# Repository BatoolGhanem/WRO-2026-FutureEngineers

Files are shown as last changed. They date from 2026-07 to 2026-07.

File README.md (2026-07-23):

<div align="center">

# 🏎️ WRO Future Engineers 2026

## NextGen Minds 🇵🇸

### Birzeit University — Palestine

Autonomous Ackermann Steering Robot for the **World Robot Olympiad (WRO) Future Engineers 2026** competition.

<p>
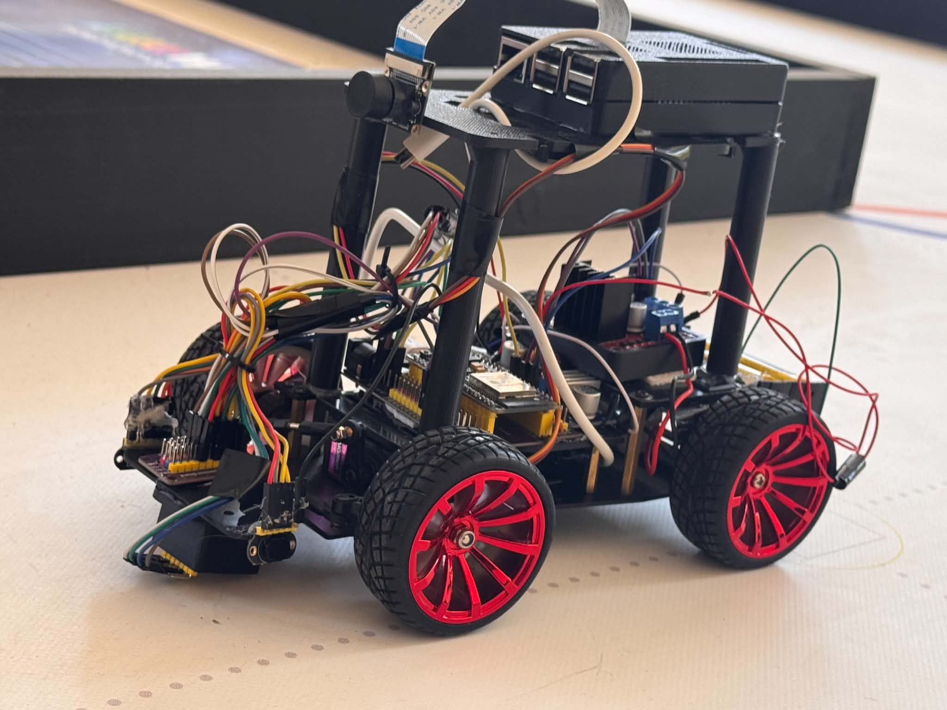
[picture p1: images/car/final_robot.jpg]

</p>

---







</div>

---

# Overview

This repository documents the complete development of our autonomous vehicle for the **WRO Future Engineers 2026** competition.

Rather than presenting only the final robot, this repository documents the complete engineering journey—from the first design discussions and component selection to mechanical assembly, electronics integration, software development, testing, calibration, and continuous improvement.

The robot is built on an Ackermann steering chassis and combines real-time embedded control using an ESP32 with higher-level vision processing on a Raspberry Pi.

---

# Robot Highlights

- Ackermann steering vehicle
- Rear-wheel drive
- ESP32 real-time controller
- Raspberry Pi vision processor
- Dual VL53L1X Time-of-Flight sensors
- MPU6050 inertial measurement unit
- TCS34725 color sensor
- Raspberry Pi Camera
- Modular hardware architecture
- UART communication between controllers
- Fully documented engineering process

---

# Competition

**Competition:** World Robot Olympiad (WRO)

**Category:** Future Engineers

**Season:** 2026

The robot is designed to complete both official challenges:

- Open Challenge
- Obstacle Challenge

---

# Team

<p align="center">
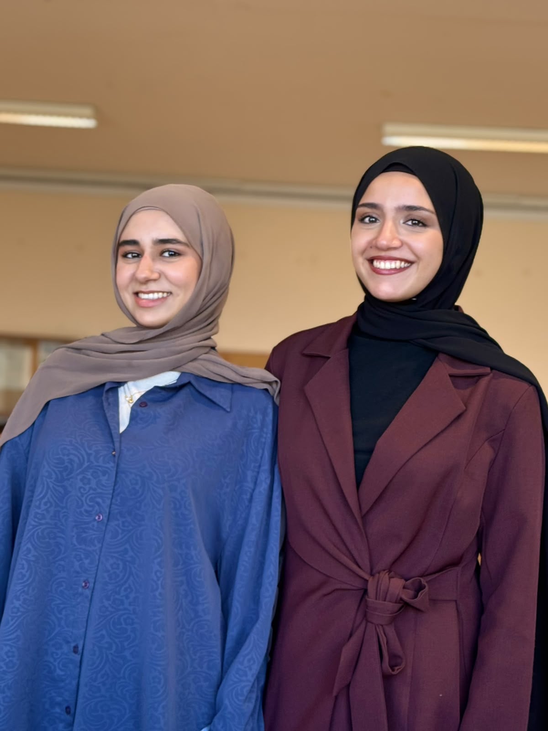
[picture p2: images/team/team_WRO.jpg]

</p>

We are **NextGen Minds**, a team of second-year Computer Engineering students from Birzeit University representing Palestine in the WRO Future Engineers 2026 competition.

For detailed information about our team members and responsibilities, see:

📄 **[TEAM.md](docs/TEAM.md)**

**Coach**

Osid Ali

**Institution**

Birzeit University

**Country**

Palestine 🇵🇸

---

# Robot Architecture

The robot follows a distributed architecture where each controller has a dedicated responsibility.

| Controller | Responsibilities |
|---|---|
| Raspberry Pi 3 Model B | Computer vision, obstacle detection, navigation logic |
| ESP32 DevKit V1 | Motor control, steering, sensor acquisition, real-time control |

Communication between both controllers is performed using UART serial communication.

This architecture separates computationally intensive vision algorithms from deterministic real-time vehicle control, resulting in a more reliable and modular system.

---

# Robot Specifications

| Parameter | Value |
|---|---:|
| Steering | Ackermann |
| Drive | Rear-Wheel Drive |
| Main Controller | ESP32 DevKit V1 |
| Vision Processor | Raspberry Pi 3 Model B |
| Camera | Raspberry Pi Camera |
| Motor Driver | L298N |
| Steering Servo | MG996R |
| Distance Sensors | 2 × VL53L1X |
| IMU | MPU6050 |
| Color Sensor | TCS34725 |
| Power System | 2S Li-ion Battery + XL4015 Buck Converter |

---

# Repository Structure

```text
WRO-2026-FutureEngineers/

├── README.md

├── docs/
│   ├── HARDWARE.md
│   ├── SOFTWARE.md
│   ├── WIRING.md
│   ├── TESTING.md
│   ├── CALIBRATION.md
│   ├── CALCULATIONS.md
│   ├── DECISIONS.md
│   ├── JOURNAL.md
│   └── TEAM.md

├── src/
│   ├── esp32/
│   └── raspberry_pi/

├── images/

└── videos/
```
# Hardware

The robot combines commercially available components with custom mechanical mounts to create a reliable and modular autonomous platform.

Every hardware component was selected after evaluating multiple alternatives based on performance, reliability, compatibility, availability, and future scalability.

For detailed specifications and engineering justification, see:

📄 **[Hardware Documentation](docs/HARDWARE.md)**

📄 **[Engineering Decisions](docs/DECISIONS.md)**

---

## Main Components

| Component | Model |
|---|---|
| Main Controller | ESP32 DevKit V1 |
| Vision Processor | Raspberry Pi 3 Model B |
| Camera | Raspberry Pi Camera Module |
| Motor Driver | L298N |
| Steering Servo | MG996R |
| Drive Motor | JGA25-370 DC Gear Motor |
| Distance Sensors | 2 × VL53L1X |
| IMU | MPU6050 |
| Color Sensor | TCS34725 |
| Power Supply | 2S Li-ion Battery |
| Voltage Regulator | XL4015 Buck Converter |

---

## Electronics

The electronics were designed around a distributed architecture.

The ESP32 performs all real-time tasks including:

- Steering control
- Motor control
- Sensor acquisition
- Safety functions

The Raspberry Pi performs computationally intensive tasks including:

- Camera processing
- Object detection
- Navigation logic
- Decision making

Both controllers communicate through a UART interface.

Complete wiring documentation is available in:

📄 **[WIRING.md](docs/WIRING.md)**

---

# Software

The software was developed as independent modules instead of a single monolithic program.

This modular design improves:

- Maintainability
- Debugging
- Reliability
- Future expansion

A clear separation exists between high-level vision processing and low-level embedded control.

For the complete software description, see:

📄 **[SOFTWARE.md](docs/SOFTWARE.md)**

---

## ESP32 Responsibilities

- Motor control
- Steering control
- Wall following
- Reading VL53L1X sensors
- Reading MPU6050
- Reading TCS34725
- Executing movement commands
- Communication with Raspberry Pi

---

## Raspberry Pi Responsibilities

- Image acquisition
- Computer vision
- Obstacle detection
- Navigation decisions
- UART communication

---

# Robot Capabilities

The robot is capable of:

- Autonomous driving
- Wall following
- Accurate 90° turns
- Obstacle detection
- Color marker recognition
- Heading correction using the IMU
- Real-time sensor fusion
- Modular software execution

---

# Engineering Documentation

This repository includes complete engineering documentation covering every stage of development.

| Document | Description |
|---|---|
| HARDWARE.md | Hardware components and specifications |
| SOFTWARE.md | Software architecture |
| WIRING.md | Electrical wiring diagram |
| DECISIONS.md | Engineering decision process |
| CALCULATIONS.md | Engineering calculations |
| TESTING.md | Testing methodology |
| CALIBRATION.md | Calibration procedure |
| JOURNAL.md | Complete development history |
| TEAM.md | Team information |

---

# Development Process

The robot was developed through several engineering stages:

1. Research and planning
2. Component selection
3. Mechanical assembly
4. Electronics integration
5. Embedded software development
6. Computer vision development
7. Testing and debugging
8. Calibration
9. Performance optimization
10. Final validation

Each stage is documented in the Engineering Journal.

📄 **[JOURNAL.md](docs/JOURNAL.md)**

---

# Design Philosophy

Our goal was not simply to build a robot capable of completing the competition.

Instead, we focused on developing a modular engineering platform that could be continuously improved throughout the season.

Every major engineering decision—including hardware selection, software architecture, sensor placement, power distribution, and control strategy—was supported by research, testing, and repeated validation.

---

# Competition Challenges

## 🟢 Open Challenge

The Open Challenge focuses on autonomous navigation around the track for three complete laps without human intervention.

### Main Objectives

- Stable wall following
- Accurate 90° turns
- Reliable lap counting
- Consistent vehicle speed
- Heading correction using the IMU
- High repeatability

The robot combines dual VL53L1X distance sensors with IMU feedback to maintain a stable trajectory throughout the course.

---

## 🔴 Obstacle Challenge

The Obstacle Challenge extends the robot's capabilities by introducing dynamic navigation using computer vision.

### Planned Features

- Red pillar detection
- Green pillar detection
- Real-time obstacle avoidance
- Dynamic path planning
- Camera-based navigation
- Vision-assisted steering

These features are executed on the Raspberry Pi while the ESP32 continues handling all real-time vehicle control.

---

# Testing & Validation

Every subsystem was tested independently before full integration.

Testing included:

- Mechanical verification
- Steering calibration
- Motor testing
- Power stability
- Sensor validation
- UART communication
- Wall-following accuracy
- Corner detection
- Turn consistency
- Complete autonomous runs

For detailed testing procedures:

📄 **[TESTING.md](docs/TESTING.md)**

---

# Calibration

To ensure repeatable performance, each sensor was calibrated before testing.

Calibration includes:

- MPU6050 bias correction
- VL53L1X distance verification
- Color sensor threshold adjustment
- Steering center alignment
- Motor speed tuning

Complete calibration procedure:

📄 **[CALIBRATION.md](docs/CALIBRATION.md)**

---

# Engineering Calculations

The design was supported by engineering calculations throughout the project.

Topics include:

- Robot dimensions
- Weight analysis
- Turning geometry
- Power considerations
- Safety margins

See:

📄 **[CALCULATIONS.md](docs/CALCULATIONS.md)**

---

# Engineering Decisions

Throughout development, several alternative solutions were evaluated before selecting the final design.

Examples include:

- ESP32 vs Arduino
- Raspberry Pi integration
- Sensor selection
- Power architecture
- Chassis selection
- Communication protocol

The reasoning behind every major decision is documented in:

📄 **[DECISIONS.md](docs/DECISIONS.md)**

---

# Gallery

## Final Robot

<p align="center">

</p>

---

## Robot Views

| Front | Rear |
|---|---|
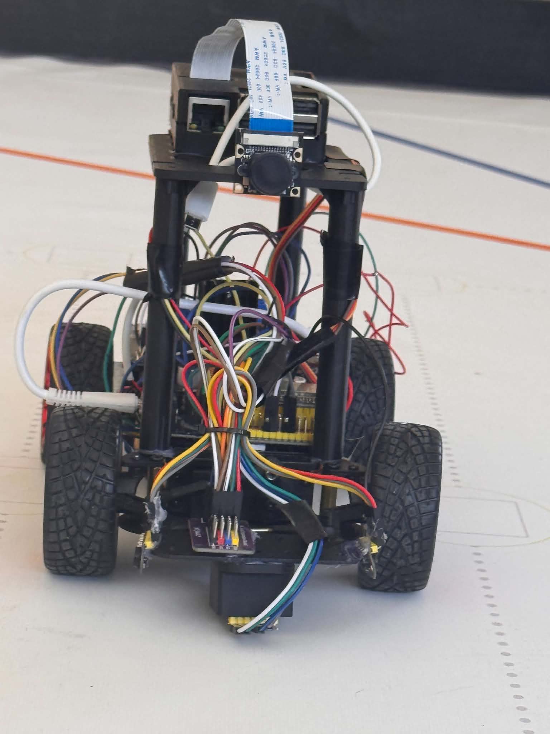
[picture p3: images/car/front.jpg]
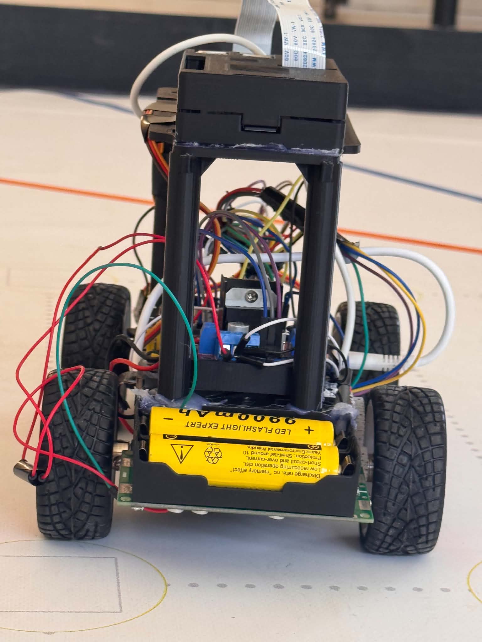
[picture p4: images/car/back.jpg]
|  |  |

| Left | Right |
|---|---|
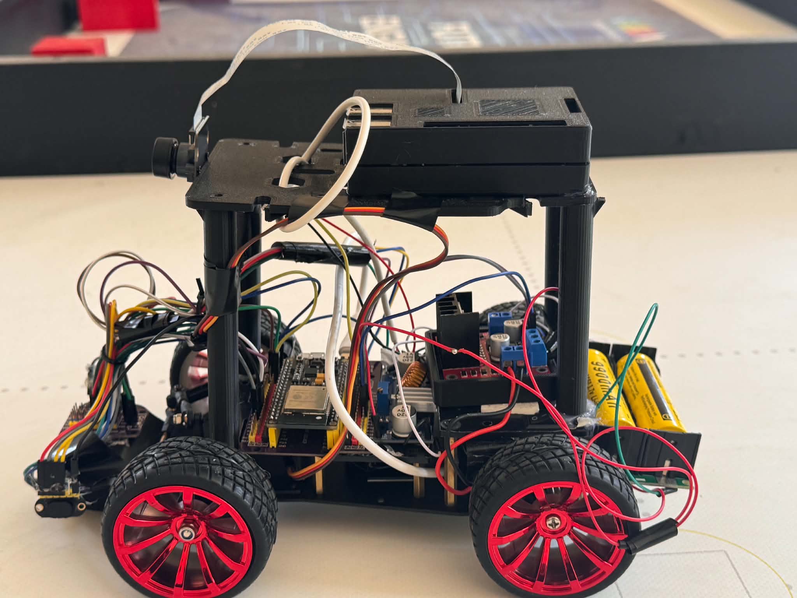
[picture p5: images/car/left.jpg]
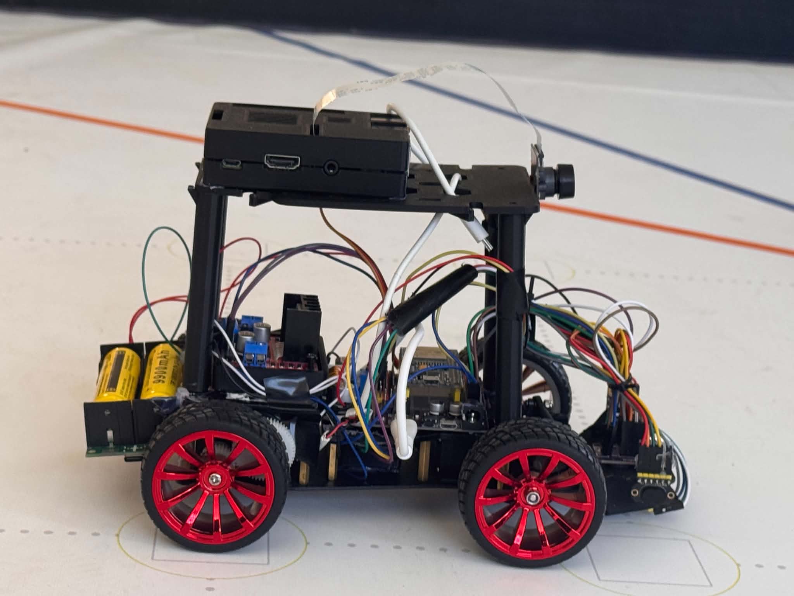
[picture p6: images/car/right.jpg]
|  |  |

| Top | Bottom |
|---|---|
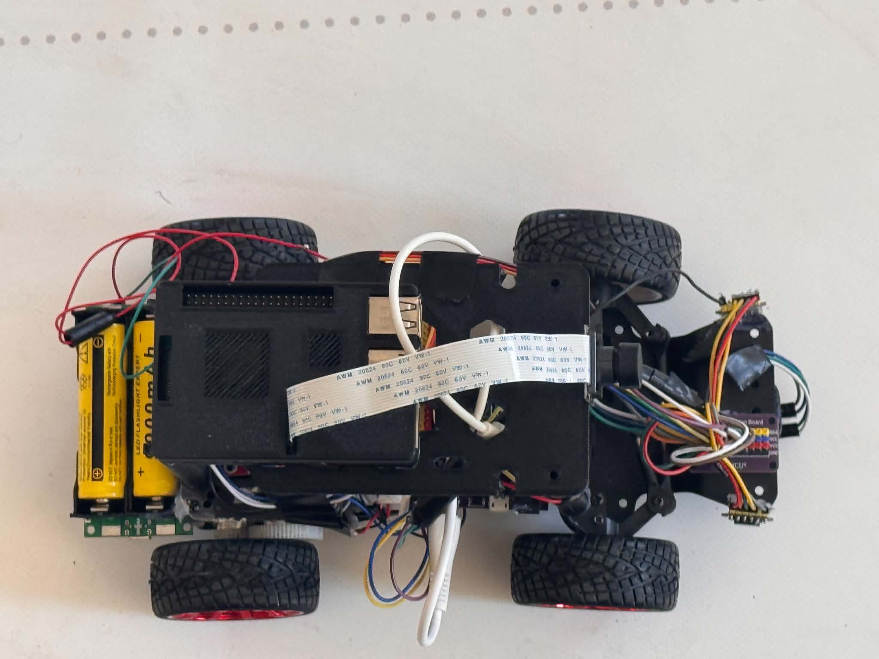
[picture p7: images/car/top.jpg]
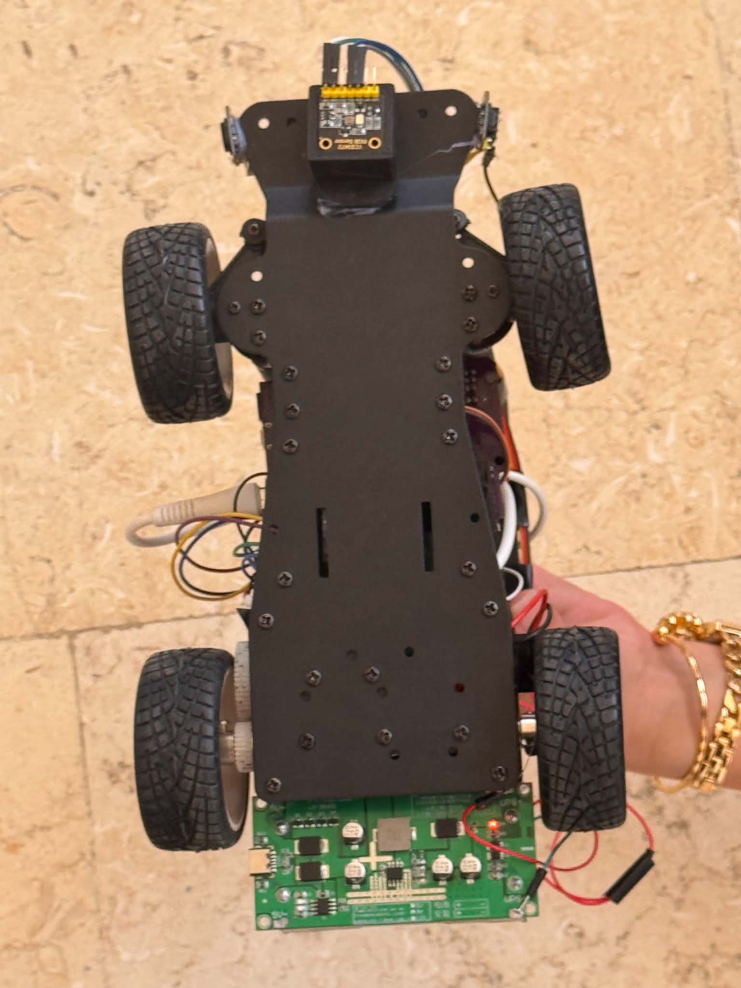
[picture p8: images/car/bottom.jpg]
|  | |

---

# Videos

The following demonstration videos are included with the project.

| Video | Description |
|---|---|
| Open Challenge | Autonomous driving demonstration |
| Obstacle Challenge | Vision-based obstacle avoidance |
| Robot Overview | Complete hardware presentation |
| Software Demo | System architecture explanation |

Videos can be found inside the **videos/** directory.

---

# Engineering Journal

This repository documents the complete development history of the project.

The journal includes:

- Planning
- Research
- Hardware assembly
- Electronics
- Programming
- Testing
- Improvements
- Final validation

📄 **[JOURNAL.md](docs/JOURNAL.md)**

---

# Project Status

| Module | Status |
|---|---|
| Mechanical Design | ✅ Completed |
| Electronics | ✅ Completed |
| Embedded Software | ✅ Completed |
| Computer Vision | 🔄 In Progress |
| Testing | 🔄 Ongoing |
| Documentation | ✅ Completed |

---

# Repository Statistics

- Complete engineering documentation
- Modular software architecture
- Fully documented hardware
- Wiring diagrams
- Calibration procedures
- Testing methodology
- Engineering calculations
- Design decisions
- Development journal
  ---

# Future Improvements

Although the robot has reached a functional and competitive state, we believe engineering is a continuous process. Future improvements may include:

- Advanced sensor fusion algorithms
- PID auto-tuning
- Vision-based localization
- AI-assisted path planning
- Custom PCB design
- Lightweight 3D-printed mechanical components
- Improved power management
- Enhanced obstacle avoidance strategies

---

# Acknowledgments

We would like to express our sincere gratitude to everyone who supported this project.

Special thanks to:

- Our coach **Osid Ali** for his continuous guidance and valuable feedback.
- **Birzeit University** for providing an inspiring learning environment.
- The **World Robot Olympiad (WRO)** organization for encouraging innovation and engineering excellence.
- Our families and friends for their encouragement throughout the project.

---

# About This Repository

This repository is intended to document the complete engineering process behind our WRO Future Engineers robot.

It includes not only the final solution, but also the research, engineering decisions, testing procedures, calibration methods, calculations, and software architecture developed throughout the season.

Our goal is to maintain a clear, transparent, and professional engineering record of the project.

---

# Repository Documentation

The complete documentation can be found in the **docs/** directory.

| Document | Description |
|---|---|
| 📄 HARDWARE.md | Hardware components and specifications |
| 📄 SOFTWARE.md | Software architecture |
| 📄 WIRING.md | Wiring and electronics |
| 📄 CALIBRATION.md | Calibration procedures |
| 📄 TESTING.md | Testing methodology |
| 📄 CALCULATIONS.md | Engineering calculations |
| 📄 DECISIONS.md | Design decisions |
| 📄 JOURNAL.md | Engineering journal |
| 📄 TEAM.md | Team information |

---

# Technologies Used

### Programming

- C++
- Python

### Embedded Systems

- ESP32 Arduino Framework
- UART Communication
- I²C Communication

### Computer Vision

- OpenCV
- Raspberry Pi Camera

### Sensors

- VL53L1X
- MPU6050
- TCS34725

### Mechanical

- Ackermann Steering
- RC Vehicle Platform

---

# License

This repository was created exclusively for the **World Robot Olympiad (WRO) Future Engineers 2026** competition.

All documentation, software, and mechanical designs were developed by **Team NextGen Minds** unless otherwise stated.

---

<div align="center">

## Thank You for Visiting Our Repository

We hope this repository clearly demonstrates our engineering process, technical decisions, and continuous development throughout the WRO Future Engineers 2026 season.

**Team NextGen Minds 🇵🇸**

**Birzeit University**

**World Robot Olympiad 2026**

⭐ If you found this project interesting, thank you for taking the time to explore our work.

</div>

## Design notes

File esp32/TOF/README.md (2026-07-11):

# TOF400C-VL53L1X Distance Sensor Validation

## Objective

The objective of this test is to validate the TOF400C-VL53L1X Time-of-Flight distance sensor before integrating it into the WRO Future Engineers autonomous vehicle.

The sensor is intended to support:

- Obstacle detection
- Wall distance estimation
- Safety monitoring
- Emergency stop behavior
- Navigation correction

---

# Hardware

## Sensor Model

The tested sensor module is labeled:

```text
TOF400C-VL53L1X
```

The module pins are:

```text
VIN
GND
SDA
SCL
INT
SHUT
```

---

# Wiring

For single-sensor testing:

| TOF400C-VL53L1X | ESP32 |
|---|---|
| VIN | 3.3V |
| GND | GND |
| SDA | GPIO21 |
| SCL | GPIO22 |
| SHUT | GPIO3 |
| INT | GPIO2 |

Communication protocol:

- I2C

---

# Test 1: I2C Scanner

## Purpose

The first step was to verify that the ESP32 could detect the sensor through the I2C bus before attempting distance measurements.

## Result

The sensor was successfully detected at the default I2C address:

```text
0x29
```

Example output:

```text
I2C device found at address 0x29
```

This confirmed that:

- Power connections were correct.
- SDA and SCL wiring were correct.
- The ESP32 could communicate with the sensor through the I2C bus.

---

# Challenge Encountered

Although the sensor was correctly detected by the I2C scanner, it could not be initialized using the first software libraries that were tested.

During development, several attempts produced errors such as:

```text
VL53L1X library initialization failed
```

and

```text
i2cRead returned Error 263
```

This indicated that the hardware was functioning correctly, but the selected software libraries were not fully compatible with the TOF400C-VL53L1X module.

---

# Engineering Investigation

To identify the cause of the problem, several debugging steps were performed:

- Verified the wiring multiple times.
- Tested the sensor using an I2C Scanner.
- Confirmed that the device always appeared at address **0x29**.
- Tested different VL53L1X Arduino libraries.
- Compared initialization methods.
- Reviewed the sensor documentation and pin configuration.

The investigation showed that the problem was software-related rather than hardware-related.

---

# Solution

The issue was resolved by switching to the **Adafruit VL53L1X** library and using the correct initialization procedure together with the SHUT and INT pins.

After updating the software implementation:

- The sensor initialized successfully.
- Continuous ranging started correctly.
- Stable distance measurements were obtained.

---

# Validation Result

The ESP32 successfully:

- Initialized the sensor.
- Started continuous ranging.
- Read distance measurements in millimeters.
- Produced stable and repeatable readings.

Example output:

```text
Adafruit VL53L1X sensor demo

VL53L1X sensor OK!

Sensor ID: 0xEACC

Ranging started

Distance: 245 mm
Distance: 248 mm
Distance: 251 mm
```

---

# Engineering Notes

This debugging process demonstrated the importance of validating both hardware and software compatibility.

Although the sensor responded correctly on the I2C bus, additional investigation was required before reliable distance measurements could be achieved.

Documenting unsuccessful attempts helped identify the correct software solution and improved the reproducibility of the project.

---

# Future Integration

The validated sensor will later be integrated with:

- Sensor Manager
- Obstacle Avoidance
- Wall Detection
- Navigation State Machine
- Safety System
- Emergency Stop Logic

The final robot will use **two TOF400C-VL53L1X sensors**.

Each sensor will be initialized independently using the SHUT pins before assigning separate I2C addresses for simultaneous operation.

---

# Reproducibility Notes

To reproduce this validation:

1. Connect the sensor according to the wiring table.
2. Upload the validation program using the Adafruit VL53L1X library.
3. Verify successful initialization.
4. Confirm continuous distance measurements.
5. Repeat the test using different object distances.

---

# Engineering Conclusion

The TOF400C-VL53L1X sensor was successfully validated after resolving a software compatibility issue during development.

The final implementation provides reliable initialization, stable distance measurements, and a suitable foundation for integrating dual TOF sensors into the final WRO Future Engineers autonomous vehicle.

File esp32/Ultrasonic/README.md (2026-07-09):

# HC-SR04 Ultrasonic Sensor Validation

## Objective

The objective of this test is to validate the HC-SR04 ultrasonic distance sensor before integrating it into the WRO Future Engineers autonomous vehicle.

The ultrasonic sensor is intended to support:

- Front obstacle detection
- Distance estimation
- Collision avoidance
- Safety monitoring

---

# Engineering Decision

The HC-SR04 ultrasonic sensor was used as a temporary prototype during the early development phase.

While the TOF400C-VL53L1X sensors are planned to be the primary distance sensors for the final robot, additional software validation and integration are still under investigation.

To allow continuous development of the obstacle detection algorithms without delaying the project, the HC-SR04 was selected as an initial replacement for testing.

This approach allows the navigation, obstacle avoidance, and control software to be developed and validated independently while work on the TOF sensors continues.

The HC-SR04 will be replaced by the TOF sensors once their initialization and communication have been fully validated.
---

# Hardware

## Components

- ESP32 DevKit V1
- HC-SR04 Ultrasonic Sensor
- Jumper wires

---

# Wiring

| HC-SR04 | ESP32 |
|---|---|
| VCC | 5V |
| GND | GND |
| TRIG | GPIO32 |
| ECHO | GPIO33* |

\*During early validation, ECHO was connected directly to the ESP32 for a short functional test. For permanent integration, a voltage divider or logic level shifter should be used because the HC-SR04 outputs a 5V logic signal.

---

# Software Description

The validation program performs the following operations:

1. Generates a 10 µs trigger pulse.
2. Measures the echo pulse duration.
3. Calculates the distance in centimeters.
4. Displays the measured distance through the Serial Monitor.
5. Repeats the measurement continuously.

---

# Test Procedure

1. Connect the sensor according to the wiring table.
2. Upload the validation program.
3. Open the Serial Monitor at **115200 baud**.
4. Place an object at different distances.
5. Verify that the measured distance changes accordingly.

---

# Expected Output

Example Serial Monitor output:

```text
HC-SR04 Ultrasonic Test Started

Distance: 18.4 cm
Distance: 24.7 cm
Distance: 39.2 cm
Distance: 61.8 cm
```

---

# Test Results

The sensor successfully detected nearby objects and continuously reported distance measurements.

The measured values changed consistently as the target object moved closer or farther from the sensor.

---

# Engineering Notes

The HC-SR04 measures distance by transmitting ultrasonic pulses and measuring the echo return time.

The measured pulse duration is converted into distance using the speed of sound.

For final robot integration, the ECHO output will be connected through a voltage divider to ensure compatibility with the ESP32's 3.3V GPIO inputs.

---

# Future Integration

The ultrasonic sensor will later be integrated with:

- Obstacle Avoidance
- Navigation State Machine
- Emergency Stop Logic
- Autonomous Driving Strategy

Future improvements include:

- Sensor filtering
- Moving average smoothing
- Multi-sensor fusion with the IMU and vision system
- Safety threshold tuning

---

# Engineering Conclusion

The HC-SR04 successfully completed functional validation and was selected as the primary distance sensor for the current development stage.

Its reliability, simple interface, and stable measurements make it suitable for integration into the autonomous navigation system.

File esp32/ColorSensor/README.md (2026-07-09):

# TCS34725 Color Sensor Validation Test

## Objective

The objective of this test is to validate the functionality of the TCS34725 RGB Color Sensor before integrating it into the autonomous vehicle software.

This test verifies:

- Correct I2C communication
- Successful sensor initialization
- Stable RGB measurements
- Reliable color recognition
- Live sensor response under different colored surfaces

---

# Engineering Decision

The TCS34725 color sensor was selected because it provides accurate RGB and clear light intensity measurements using an integrated IR filter.

For the WRO Future Engineers robot, the color sensor is used to identify colored navigation markers placed on the competition field.

The sensor communicates directly with the ESP32 through the I2C bus, allowing fast and reliable color detection during autonomous operation.

---

# Hardware Configuration

## Components

- ESP32 DevKit V1
- TCS34725 Color Sensor
- Jumper Wires

---

## Wiring

| TCS34725 | ESP32 |
|---|---|
| VIN | 3.3V |
| GND | GND |
| SDA | GPIO21 |
| SCL | GPIO22 |

Communication protocol:

- I2C

---

# Software Description

The test program performs the following operations:

1. Initializes Serial communication.
2. Initializes the I2C bus.
3. Detects the TCS34725 sensor.
4. Reads:
   - Red value
   - Green value
   - Blue value
   - Clear light intensity
5. Classifies the detected surface color.
6. Displays the measurements through the Serial Monitor.

---

# Test Procedure

1. Connect the sensor according to the wiring table.
2. Upload the validation program.
3. Open the Serial Monitor at **115200 baud**.
4. Place different colored objects beneath the sensor.
5. Verify that the RGB values and detected color change correctly.

---

# Expected Output

```text
TCS34725 Color Sensor Test

TCS34725 detected successfully.

R: 125
G: 42
B: 37
Clear: 215
Detected: RED
```

Example outputs may include:

```text
Detected: RED
Detected: GREEN
Detected: BLUE
Detected: WHITE
Detected: UNKNOWN
```

---

# Test Results

The ESP32 successfully initialized the TCS34725 through the I2C bus.

The sensor continuously measured RGB values and clear light intensity.

Different colored surfaces produced distinct RGB readings, allowing successful color classification.

---

# Engineering Notes

The TCS34725 shares the same I2C bus with the MPU6050 and the VL53L1X sensors.

Using a shared I2C bus reduces wiring complexity while maintaining reliable communication with multiple sensors.

During testing, different colored objects were placed beneath the sensor to verify repeatable measurements under consistent lighting conditions.

---

# Future Integration

The color sensor will later be integrated with:

- Navigation State Machine
- Sensor Manager
- Marker Detection Logic
- Raspberry Pi Vision System
- Autonomous Driving Strategy

Future improvements include:

- Dynamic color calibration
- Ambient light compensation
- Adaptive threshold tuning
- Improved marker classification under varying lighting conditions

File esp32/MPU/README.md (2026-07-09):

# MPU6050 Validation Test

## Objective

The purpose of this test is to validate the functionality of the MPU6050 Inertial Measurement Unit (IMU) before integrating it into the complete WRO Future Engineers autonomous vehicle software.

The objective is to verify:

- Correct I2C communication
- Stable accelerometer measurements
- Stable gyroscope measurements
- Reliable sensor initialization

---

# Engineering Rationale

The MPU6050 was selected because it provides both acceleration and angular velocity measurements in a compact and lightweight package.

Although lane following is mainly performed using computer vision on the Raspberry Pi, the IMU provides additional information about the vehicle's motion that can later be used for:

- Heading estimation
- Motion analysis
- Steering stabilization
- Future sensor fusion

---

# Hardware Configuration

## Components

- ESP32 DevKit V1
- MPU6050 IMU

## Wiring

| MPU6050 | ESP32 |
|---|---|
| VCC | 3.3V |
| GND | GND |
| SDA | GPIO21 |
| SCL | GPIO22 |

Communication protocol:

- I2C

---

# Software Description

The software performs the following steps:

1. Initialize Serial communication.
2. Initialize the I2C bus.
3. Detect the MPU6050.
4. Configure:
   - Accelerometer Range
   - Gyroscope Range
   - Digital Filter
5. Continuously read:
   - Acceleration
   - Angular velocity
   - Temperature
6. Display the measurements through Serial Monitor.

---

# Test Procedure

1. Connect the sensor according to the wiring diagram.
2. Upload the validation program.
3. Open the Serial Monitor at 115200 baud.
4. Verify successful initialization.
5. Move the sensor in different directions.
6. Confirm that all measurements change smoothly.

---

# Expected Result

Successful initialization:

```text
MPU6050 found!
```

Live measurements:

```text
Acceleration
Gyroscope
Temperature
```

The sensor should continuously update without communication errors.

---

# Validation Result

The sensor initialized successfully.

The ESP32 established stable I2C communication.

Acceleration and gyroscope measurements responded correctly to physical movement.

No communication failures were observed during testing.

---

# Engineering Notes

During development, the default ESP32 I2C pins were used:

- SDA → GPIO21
- SCL → GPIO22

Using the default hardware I2C pins simplified debugging and ensured compatibility with the remaining I2C sensors that will be integrated later in the project.

---

# Future Integration

This module will become part of the final software architecture.

The IMU data will later be combined with:

- Steering Controller
- Navigation State Machine
- Safety System
- Computer Vision decisions from the Raspberry Pi

to improve vehicle stability and navigation accuracy.

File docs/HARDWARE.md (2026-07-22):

# Hardware Design

## Overview

The hardware platform of our WRO Future Engineers robot was designed to achieve reliable autonomous navigation while maintaining a compact, modular, and serviceable mechanical structure.

The robot combines embedded control, computer vision, distance sensing, inertial sensing, and color detection into a single integrated system. Instead of relying on a single controller for every task, the design separates low-level real-time control from computationally intensive image processing. This architecture allows each subsystem to perform its task efficiently without affecting the stability of the others.

The mechanical platform is based on a commercially available Ackermann steering RC chassis. A custom 3D-printed upper layer was added to provide sufficient mounting space for the Raspberry Pi, camera, and additional electronics while maintaining a clean internal layout.

Throughout the design process, every component was selected according to engineering criteria rather than convenience. The primary design objectives were:

- Reliable autonomous operation
- Accurate wall-distance measurement
- Stable steering performance
- Modular construction
- Easy maintenance
- Efficient power distribution
- Expandability for future improvements
- Mechanical robustness during repeated testing

The final robot integrates the following major subsystems:

- ESP32 real-time controller
- Raspberry Pi 3 Model B+
- Raspberry Pi Camera
- Two VL53L1X Time-of-Flight sensors
- MPU6050 Inertial Measurement Unit
- TCS34725 RGB Color Sensor
- MG996R steering servo
- Geared DC drive motor
- L298N motor driver
- XL4015 buck converter
- 2S Li-ion battery
- Ackermann steering chassis
- Custom and third-party 3D-printed mechanical parts

---

# Design Philosophy

Rather than designing every subsystem independently, the robot was developed as one integrated engineering system.

Every hardware decision considered its influence on:

- navigation accuracy,
- mechanical stability,
- electrical reliability,
- software implementation,
- future maintenance,
- and competition robustness.

For example, the camera position affects obstacle detection, but also influences weight distribution and cable routing. Likewise, the location of the distance sensors directly affects navigation accuracy, while also limiting the available space for other components.

This systems-engineering approach reduced unnecessary redesigns during development and simplified later software calibration.

---

# Hardware Architecture

The robot uses a distributed processing architecture consisting of two computing units.

The ESP32 performs all real-time operations including:

- sensor acquisition,
- steering control,
- motor control,
- navigation state management,
- and communication with the Raspberry Pi.

The Raspberry Pi is dedicated to computer vision. Separating image processing from the motion controller prevents camera-processing delays from affecting steering performance.

This architecture increases reliability because the control loop continues operating with deterministic timing regardless of camera processing load.

```
                        Raspberry Pi Camera
                                │
                                │
                       Raspberry Pi 3B+
                                │
                     High-level vision results
                                │
                                ▼
                           ESP32 DevKit
      ┌───────────────┬───────────────┬──────────────┐
      │               │               │              │
  VL53L1X         MPU6050         TCS34725       Motor Driver
      │               │               │              │
      └───────────────┴───────────────┴──────────────┘
                                │
                      Steering Servo + DC Motor
```

This separation also simplifies software development because the embedded firmware and computer-vision software can be developed and tested independently.

---

# Hardware Summary

| Category | Component | Model |
|---|---|---|
| Main Controller | ESP32 DevKit V1 | ESP32 |
| Vision Computer | Raspberry Pi | Raspberry Pi 3 Model B+ |
| Camera | Raspberry Pi Camera | CSI Camera |
| Distance Sensors | Time-of-Flight Sensors | 2 × VL53L1X |
| IMU | Gyroscope + Accelerometer | MPU6050 |
| Color Sensor | RGB Sensor | TCS34725 |
| Steering | Servo Motor | MG996R |
| Drive Motor | Geared DC Motor | Included with chassis |
| Motor Driver | Dual H-Bridge | L298N |
| Voltage Regulation | Buck Converter | XL4015 |
| Battery | Rechargeable Battery | 2S Li-ion |
| Chassis | Ackermann RC Chassis | Commercial Platform |

---

# Engineering Objectives

The hardware was designed to satisfy several engineering requirements simultaneously.

## Reliability

All critical electronic modules are securely mounted using dedicated holders or enclosures to reduce movement caused by vibration.

Electrical connections are mechanically supported to prevent accidental disconnection during repeated runs.

## Modularity

The robot can be disassembled without rebuilding the complete vehicle.

Most electronic modules can be removed individually for replacement, maintenance, or debugging.

## Weight Distribution

Heavy components such as the battery are positioned as low as practical to improve stability while cornering.

The additional upper layer was designed primarily for lightweight electronics to minimize the increase in the center of gravity.

## Cable Management

Power wiring and signal wiring are routed in an organized manner to reduce clutter and simplify maintenance.

Keeping cables organized also reduces the risk of obstructing the camera or distance sensors during operation.

## Expandability
The layered mechanical structure allows additional modules to be installed in future versions without redesigning the complete robot.
# Main Controller — ESP32 DevKit V1

The ESP32 DevKit V1 is the main real-time controller of the vehicle.

It is responsible for reading sensors, processing navigation data, controlling the steering servo, controlling the drive motor, and managing communication with the Raspberry Pi.

The ESP32 was selected because it provides a strong balance between processing performance, size, connectivity, and available input/output pins.

## Main Responsibilities

The ESP32 performs the following tasks:

- Reading both VL53L1X distance sensors
- Reading the MPU6050 inertial measurement unit
- Reading the TCS34725 color sensor
- Controlling the MG996R steering servo
- Controlling the L298N motor driver
- Executing wall-following behavior
- Detecting turns and track changes
- Managing the navigation state machine
- Filtering unstable sensor readings
- Receiving vision information from the Raspberry Pi

## Why the ESP32 Was Selected

Several controllers could have been used, but the ESP32 provided the best balance for this robot.

| Controller | Advantages | Limitations |
|---|---|---|
| Arduino Uno | Simple, low cost, and widely supported | Limited memory, lower processing speed, and fewer communication options |
| Arduino Mega | More input/output pins | Larger size and lower processing performance |
| Raspberry Pi only | High processing power | Less suitable for deterministic low-level motor control |
| ESP32 DevKit V1 | Fast processing, compact size, multiple communication interfaces, and good real-time performance | Requires careful 3.3 V logic handling and proper pin selection |

The ESP32 is more suitable for time-sensitive control than relying only on the Raspberry Pi.

## Engineering Considerations

The ESP32 operates using 3.3 V logic. Therefore, all connected signal lines must remain within safe voltage levels.

Careful pin selection is also required because some ESP32 pins have special boot or startup functions.

The ESP32 was mounted in a stable position and connected using short, organized signal wires to reduce the possibility of loose connections.

---

# Vision Computer — Raspberry Pi 3 Model B+

The Raspberry Pi 3 Model B+ is used as the high-level vision-processing computer.

Its main role is to process camera images and identify visual objects required for the Obstacle Challenge.

## Main Responsibilities

The Raspberry Pi is responsible for:

- Capturing camera frames
- Running Python-based vision software
- Processing images using OpenCV
- Detecting red and green traffic pillars
- Estimating the horizontal position of detected objects
- Supporting obstacle-avoidance decisions
- Sending higher-level information to the ESP32

## Why the Raspberry Pi Was Selected

Computer vision requires more memory and processing power than the ESP32 can efficiently provide.

The Raspberry Pi was selected because it:

- Supports Linux
- Supports Python
- Supports OpenCV
- Provides sufficient processing power for real-time camera analysis
- Can communicate with the ESP32
- Is compatible with common camera modules
- Allows rapid software testing and debugging

## Distributed Processing Advantage

The Raspberry Pi and ESP32 perform different tasks.

The Raspberry Pi handles high-level vision processing, while the ESP32 handles low-level control.

This reduces the chance that image-processing delays will interrupt steering or motor control.

## Trade-Offs

The Raspberry Pi increases:

- Power consumption
- Total vehicle weight
- Boot time
- Software complexity
- Cooling and mounting requirements

However, these disadvantages are acceptable because camera processing is essential for the Obstacle Challenge.

---

# Camera System

The camera is connected to the Raspberry Pi and provides the forward-facing visual input required for object detection.

The camera is positioned on the upper section of the robot to provide a clear view of the track and traffic pillars.

## Camera Functions

The camera system is used to:

- Detect red traffic pillars
- Detect green traffic pillars
- Estimate object position in the image
- Support left-right obstacle decisions
- Observe the track ahead of the vehicle

## Camera Mounting Requirements

The camera mount must provide:

- A stable angle
- A clear field of view
- Minimal vibration
- No obstruction from wires or electronic components
- Mechanical protection
- Easy access for adjustment

A small change in camera angle can affect the apparent position of objects in the image. Therefore, the mount must prevent unwanted movement during operation.

## Vision Reliability Considerations

Camera-based detection can be affected by:

- Lighting conditions
- Shadows
- Reflections
- Motion blur
- Camera vibration
- Changes in object distance
- Incorrect exposure
- Background colors

The vision software should therefore use calibrated color ranges and geometric filtering instead of relying on raw color values alone.

---

# Distance Sensing — Two VL53L1X Sensors

The robot uses two VL53L1X Time-of-Flight distance sensors.

These sensors measure distance using infrared light and are used to observe surrounding walls and track geometry.

## Main Uses

The VL53L1X sensors support:

- Wall-distance measurement
- Wall-following
- Detecting sudden distance changes
- Detecting openings
- Supporting corner detection
- Comparing the vehicle position with nearby walls
- Improving navigation stability

## Why Two Sensors Are Used

A single sensor provides only one distance measurement.

Using two sensors gives the robot more information about the surrounding geometry and helps reduce dependence on one reading.

The two readings can be used to:

- Compare wall-distance changes
- Detect whether the robot is moving toward or away from a wall
- Identify the beginning or end of a wall
- Support more stable turning decisions
- Reject clearly invalid readings

## Why VL53L1X Was Selected

Ultrasonic sensors were considered, but Time-of-Flight sensing was more suitable for the compact vehicle.

| Feature | Ultrasonic Sensor | VL53L1X |
|---|---|---|
| Measurement method | Reflected sound | Reflected infrared light |
| Beam width | Relatively wide | More focused |
| Size | Usually larger | Compact |
| Interface | Trigger and echo | I²C |
| Suitability for compact robot | Moderate | High |
| Final use | Not used | Selected |

## Sensor Limitations

VL53L1X readings may be affected by:

- Dark surfaces
- Highly reflective surfaces
- Incorrect sensor angle
- Excessive distance
- Very short distance
- Vibration
- Partial obstruction
- Seeing a different wall during a turn

The software should not react to every individual reading.

Instead, it should validate, filter, and compare measurements over time.

## Mounting Considerations

The sensor mounts must:

- Keep the sensors rigid
- Maintain the selected angle
- Prevent chassis parts from entering the field of view
- Avoid interference from wires
- Allow repeated measurements from the same reference position

The final sensor position should be documented with photographs and direction arrows.

---

# Inertial Measurement Unit — MPU6050

The MPU6050 is a six-axis inertial measurement unit containing:

- A three-axis gyroscope
- A three-axis accelerometer

The gyroscope provides rotational-rate information, while the accelerometer measures linear acceleration and gravity direction.

## Main Uses

The MPU6050 is used to:

- Detect angular movement
- Support turn detection
- Estimate heading change
- Improve turn repeatability
- Confirm that the vehicle is rotating
- Support future sensor-fusion improvements

## Why the MPU6050 Was Selected

The MPU6050 is:

- Compact
- Widely available
- Easy to connect using I²C
- Suitable for measuring rotational motion
- Supported by many software libraries

## Sensor Drift

Gyroscopes do not produce perfectly zero output when stationary.

This small bias accumulates over time and causes drift if angular velocity is integrated continuously.

For this reason:

- The sensor is calibrated before motion begins
- Initial bias is measured while the robot is stationary
- The IMU is not used as the only navigation reference
- Distance and color sensors are used as complementary information

## Mounting Position

The MPU6050 should be mounted:

- Firmly
- Parallel to the vehicle frame
- Away from loose mechanical parts
- Near the central area of the robot when possible
- In a position that does not flex or vibrate independently

---

# Floor Color Sensor — TCS34725

The TCS34725 is an RGB color sensor used to detect colored floor markings.

It measures:

- Red intensity
- Green intensity
- Blue intensity
- Clear-light intensity

## Main Uses

The sensor is used to:

- Detect orange floor markings
- Detect blue floor markings
- Determine the driving direction
- Trigger navigation-state changes
- Support lap or corner logic

## Why a Dedicated Color Sensor Was Used

Using the camera alone to detect floor markings would require the floor area to remain visible and would increase processing complexity.

A downward-facing color sensor provides a direct and fast measurement close to the track surface.

## Mounting Requirements

The sensor must be mounted:

- Facing downward
- At a consistent height
- Protected from direct ambient light
- Clear of the chassis
- Close enough to the surface for strong readings
- High enough to avoid contact with the track

The 3D-printed cover reduces external-light interference and helps keep the sensor position stable.

## Calibration Requirements

Raw color values depend on:

- Lighting
- Sensor height
- Surface texture
- Shadows
- Sensor gain
- Integration time

The software should therefore use calibrated ratios or thresholds instead of assuming one universal raw value.

---

# Steering Servo — MG996R

The MG996R servo controls the Ackermann steering linkage.

It receives a PWM command from the ESP32 and moves the front wheels to the required steering angle.

## Why the MG996R Was Selected

The steering mechanism requires enough torque to overcome:

- Tire friction
- Mechanical resistance
- Vehicle weight
- Steering-linkage friction
- Dynamic forces during movement

A small micro servo may be lighter, but it may not provide sufficient torque for reliable steering.

| Servo Type | Advantage | Limitation |
|---|---|---|
| Micro servo | Low weight and low current | Lower torque |
| MG996R | Higher torque and metal gears | Higher current and larger size |

The MG996R was selected because steering reliability was more important than minimizing servo weight.

## Servo Calibration

The steering system requires both mechanical and software calibration.

The recommended process is:

1. Command the servo to its center position.
2. Align the front wheels mechanically.
3. Install the servo horn.
4. Adjust the steering linkage.
5. Determine the true center command.
6. Determine safe left and right limits.
7. Prevent the servo from forcing the linkage beyond its mechanical range.

The software should define:

- Steering center
- Maximum safe left angle
- Maximum safe right angle
- Normal correction range
- Turn steering angle

## Power Considerations

The MG996R can draw a high current, especially during rapid movement or mechanical load.

It must not be powered directly from an ESP32 signal pin.

It requires a suitable external power supply with a common ground shared with the ESP32.

---

# Drive Motor

The robot uses a geared DC motor included with the commercial chassis.

The gearbox reduces motor speed and increases wheel torque.

This is suitable for an autonomous robot because controlled motion and sufficient torque are more important than maximum free-running speed.

## Drive Requirements

The drive system must provide:

- Forward movement
- Adjustable speed
- Smooth acceleration
- Reliable torque while steering
- Repeatable behavior
- Reverse operation when required for testing or recovery

The drive motor is controlled through the L298N motor driver.

---

# L298N Motor Driver

The L298N is a dual H-bridge motor-driver module.

It allows the ESP32 to control the motor direction and speed without supplying motor current directly.

## Main Functions

The L298N provides:

- Forward motor control
- Reverse motor control
- PWM speed control
- Electrical separation between logic signals and motor current

## Why the L298N Was Used

The L298N was selected because it is:

- Widely available
- Easy to test
- Simple to connect
- Suitable for the installed motor during development

## Limitations

The L298N uses an older bipolar-transistor design.

Its main disadvantages are:

- Significant voltage drop
- Lower efficiency than modern MOSFET drivers
- Heat generation
- Larger physical size

These limitations should be considered when calibrating motor speed.

The effective voltage reaching the motor may be lower than the battery voltage.

## Mechanical Installation

The motor driver is installed in a dedicated 3D-printed holder to:

- Prevent movement
- Reduce connector stress
- Protect wiring
- Improve cable organization
- Simplify removal and replacement
# Power System

The robot is powered by a rechargeable 2S lithium-ion battery.

A 2S battery contains two lithium-ion cells connected in series. This provides a nominal voltage of approximately 7.4 V, while the actual voltage changes according to the battery state of charge.

The power system was designed to supply both high-current loads and sensitive electronic modules without relying on one unstable power path.

The main electrical loads are:

- Geared DC drive motor
- MG996R steering servo
- ESP32 controller
- Raspberry Pi 3 Model B+
- Camera
- VL53L1X sensors
- MPU6050
- TCS34725
- L298N motor driver
- Additional indicators and communication modules

---

## Power Distribution Architecture

The battery output is divided into two main paths:

1. A motor-power path for the L298N and drive motor
2. A regulated electronics path through the XL4015 buck converter

```text
                         2S Li-ion Battery
                                 │
                           Main Power Switch
                                 │
                 ┌───────────────┴───────────────┐
                 │                               │
                 ▼                               ▼
              L298N                          XL4015
                 │                               │
                 ▼                               ▼
          Geared DC Motor                Regulated Output
                                                 │
                       ┌─────────────────────────┼─────────────────────────┐
                       │                         │                         │
                     ESP32                  Steering Servo          Other Electronics
```

The exact final wiring and voltage connections are documented separately in [`WIRING.md`](WIRING.md).

## Why the Power Paths Are Separated

The DC motor and steering servo can draw rapidly changing current.

These current changes may cause:

- Voltage drops
- Electrical noise
- ESP32 resets
- Raspberry Pi instability
- Incorrect sensor readings
- Communication errors

Using a dedicated regulated supply for the sensitive electronics helps reduce the effect of motor-load variations.

All modules still require a common electrical ground so that control signals share the same voltage reference.

## Common Ground

The grounds of the following modules are connected together:

- Battery
- ESP32
- Raspberry Pi communication interface
- L298N
- XL4015
- Steering servo
- Sensors

Without a common ground, PWM signals, motor-control signals, and communication signals may not be interpreted correctly.

---

# XL4015 Buck Converter

The XL4015 is an adjustable DC step-down converter.

It reduces the battery voltage to a stable output voltage suitable for the electronic modules.

## Why Voltage Regulation Is Required

The battery voltage is not constant.

A fully charged 2S lithium-ion battery has a higher voltage than its nominal value, and the voltage gradually decreases during operation.

Sensitive components should not depend directly on this changing voltage.

The buck converter provides a more stable supply and helps protect the control electronics from excessive voltage.

## Reasons for Selecting the XL4015

The XL4015 was selected because it provides:

- Adjustable output voltage
- Suitable current capability
- Good availability
- Simple physical integration
- A more efficient solution than linear regulation
- Sufficient capacity for the intended electronic load when correctly cooled and adjusted

## Converter Adjustment Procedure

Before connecting sensitive electronics, the converter is adjusted using the following process:

1. Disconnect the ESP32, Raspberry Pi, servo, and sensors.
2. Connect the battery to the XL4015 input.
3. Connect a multimeter to the converter output.
4. Turn the adjustment potentiometer gradually.
5. Measure the output voltage continuously.
6. Stop when the required voltage is reached.
7. Verify the output again before connecting the electronics.
8. Test the voltage under load.
9. Confirm that the converter does not overheat during extended operation.

This procedure reduces the risk of damaging the control electronics.

## Mechanical Enclosure

The XL4015 is installed inside a two-part 3D-printed enclosure.

The enclosure consists of:

```text
XL4015_Box_P1.3MF
XL4015_Box_P2_v2.3MF
```

The enclosure provides:

- Mechanical support
- Protection from accidental contact
- Improved cable organization
- Reduced risk of short circuits
- Easier removal and replacement

Ventilation openings should remain unobstructed because the converter may produce heat under load.

---

# Battery

The vehicle uses a rechargeable 2S lithium-ion battery.

## Battery Selection Criteria

The battery was selected according to:

- Required operating voltage
- Current capability
- Physical dimensions
- Weight
- Availability
- Rechargeability
- Compatibility with the drive system

## Battery Placement

The battery is one of the heaviest components in the vehicle.

It is therefore mounted as low as practical to reduce the height of the center of gravity.

Its location should also provide:

- Secure retention
- Easy access for charging and replacement
- Short power wiring
- Protection from moving parts
- Separation from sharp edges
- Minimal effect on steering motion

The battery must not be allowed to slide during acceleration or turning because movement changes the vehicle's weight distribution and may damage the wiring.

## Lithium-Ion Safety

The following precautions are required:

- Use a charger designed for the battery configuration.
- Do not short-circuit the battery terminals.
- Do not use a swollen, damaged, or overheated battery.
- Protect the wires from mechanical damage.
- Do not leave the battery connected when the robot is stored.
- Confirm correct polarity before connection.
- Secure the battery during every run.
- Monitor battery temperature during testing.
- Avoid excessive discharge.

---

# Main Power Switch

A main power switch is installed to allow the complete vehicle to be powered on and off quickly.

The switch provides:

- A clear startup procedure
- Fast emergency power isolation
- Reduced need to disconnect the battery repeatedly
- Safer maintenance
- Easier competition preparation

The switch must be easy to reach without entering the path of moving wheels or steering parts.

---

# Commercial Ackermann Chassis

The vehicle is built on a commercially available RC chassis with front-wheel Ackermann steering.

The chassis includes the main mechanical systems required for vehicle movement:

- Main frame
- Front steering linkage
- Front and rear wheels
- Axles
- Geared drive motor
- Drivetrain
- Servo mounting area
- Structural mounting points

## Why a Commercial Chassis Was Selected

Building a complete chassis from the beginning would require significant time for:

- Steering-geometry design
- Wheel alignment
- Axle design
- Bearing selection
- Gearbox design
- Motor mounting
- Structural testing
- Manufacturing and repeated mechanical adjustment

Using a commercial platform allowed the team to begin sensor integration and autonomous-navigation development earlier.

## Engineering Trade-Off

The commercial chassis provides a reliable mechanical starting point, but it also introduces limitations.

These include:

- Fixed wheelbase
- Fixed track width
- Limited component space
- Existing mounting-hole positions
- Additional weight
- Geometry that was not designed specifically for the competition electronics

These constraints were handled using custom mechanical layers and 3D-printed holders.

---

# Ackermann Steering Geometry

Ackermann steering allows the front wheels to rotate at different angles while cornering.

During a turn, the inner wheel follows a smaller-radius path than the outer wheel. Therefore, the inner wheel should turn more sharply.

This steering geometry reduces tire scrubbing and improves the natural turning behavior of the vehicle.

The commercial chassis already includes the required mechanical linkage, so the project focused on:

- Servo centering
- Steering-limit calibration
- Linkage alignment
- Mechanical play reduction
- Selecting safe software commands
- Testing the actual turning radius

The theoretical wheel angle is not assumed to be identical to the servo command. Mechanical linkage geometry, servo horn position, tire friction, and chassis load all affect the real steering response.

For this reason, the final steering values are obtained through physical calibration.

---

# Competition Size Compliance

The WRO Future Engineers vehicle must remain within the maximum permitted dimensions.

The current international Future Engineers category lists a maximum vehicle size of:

| Dimension | Maximum |
|---|---:|
| Length | 300 mm |
| Width | 200 mm |
| Height | 300 mm |

The complete vehicle must satisfy these limits, including:

- Wheels
- Camera
- Sensor mounts
- Wires
- Screw heads
- 3D-printed holders
- Upper layers
- Any permanently installed part

The official WRO website also notes that national organizers may apply local adaptations. Therefore, the final robot must be checked against the rules supplied by the local national organizer before competition. :contentReference[oaicite:0]{index=0}

## Recommended Engineering Margin

The robot should not be designed exactly at the legal maximum.

A practical target is:

| Dimension | Legal Maximum | Recommended Design Target |
|---|---:|---:|
| Length | 300 mm | Approximately 295 mm or less |
| Width | 200 mm | Approximately 195 mm or less |
| Height | 300 mm | Approximately 295 mm or less |

This margin helps account for:

- Measurement tolerance
- Small printed-part deviations
- Protruding wires
- Screw heads
- Camera mounts
- Assembly differences
- Different measuring tools

The final vehicle should be measured in its complete competition configuration.

---

# Layered Mechanical Structure

The robot uses a multi-layer mechanical arrangement to provide sufficient space for the electronics.

This arrangement separates the drivetrain, control electronics, and vision system while preserving access for maintenance.

## Base Mechanical Layer

The lowest level contains the primary mechanical components:

- Chassis frame
- Drive motor
- Gearbox
- Axles
- Wheels
- Steering linkage
- Steering servo
- Battery where mechanically suitable

Heavy components are kept low whenever possible.

## Electronics Layer

The middle level contains modules that require organized and relatively short electrical connections.

Typical components include:

- ESP32
- L298N
- XL4015
- Power-distribution connections
- Sensor connectors
- Communication wiring

This level allows access for debugging without removing the complete upper vision assembly.

## Custom Third Layer

A custom third layer was added because the original chassis did not provide sufficient mounting area for the Raspberry Pi, camera system, and additional electronics.

The third layer was developed through the following process:

1. The available chassis dimensions were measured.
2. The mounting locations and dimensions of the electronic components were measured.
3. Required clearances were identified.
4. Component placement was planned.
5. The necessary dimensions and layout were defined by the team.
6. Zoo was used to generate the digital CAD model from these requirements.
7. The model was exported for manufacturing.
8. The printed part was installed and physically tested.
9. Component fit and cable access were evaluated.

The design requirements therefore originated from the team, while Zoo assisted in generating the CAD geometry.

## Purpose of the Third Layer

The custom layer provides:

- Additional mounting area
- Improved organization
- A stable Raspberry Pi location
- Camera mounting support
- Better cable routing
- Separation between mechanical and vision components
- Easier maintenance
- Future expansion space

## Design Constraints

The upper layer had to satisfy several requirements:

- Remain inside the competition size limits
- Avoid interference with steering
- Avoid wheel contact
- Provide access to connectors
- Maintain camera visibility
- Remain sufficiently rigid
- Minimize unnecessary weight
- Allow air circulation around electronic modules
- Provide mounting-hole compatibility
- Avoid creating sharp edges near wires

---

# Weight Distribution

Weight distribution affects steering response, traction, and cornering stability.

The design follows these principles:

- Heavy components are placed as low as practical.
- The battery is mechanically secured.
- Left-right weight imbalance is minimized.
- Upper-layer mass is kept as low as practical.
- Components are prevented from moving during operation.
- Sensor visibility is not sacrificed only to improve balance.
- Steering components are not overloaded by unnecessary front weight.

## Center of Gravity

Adding a third layer raises some components above the original chassis.

This can increase the height of the center of gravity and cause greater body movement during turns.

To reduce this effect:

- The upper layer is used mainly for lightweight electronics.
- The battery and heavier power components remain lower where possible.
- Unnecessary printed material is avoided.
- Components are mounted close to the center rather than far outside the chassis.

## Front-Rear Balance

Excessive weight over the front axle can increase steering load and servo current.

Excessive rear weight can reduce front-wheel grip and steering effectiveness.

The component layout therefore aims to maintain enough front-wheel load for steering without overloading the servo.

---

# Mechanical Rigidity

Mechanical movement can directly reduce sensing accuracy.

For example:

- A moving camera changes object position in the image.
- A rotating ToF mount changes the measured wall distance.
- A flexible color-sensor holder changes the sensor-to-floor distance.
- A loose IMU mount introduces vibration and incorrect angular measurements.

For this reason, sensor mounts are treated as functional engineering components rather than decorative parts.

Each mount should be checked for:

- Cracks
- Loose screws
- Flexibility
- Rotation
- Wire tension
- Chassis contact
- Vibration during movement

---

# Cable Management

Cable organization improves both reliability and maintainability.

The wiring is routed to:

- Avoid the wheels
- Avoid the steering linkage
- Prevent obstruction of sensors
- Reduce strain on connectors
- Keep power and signal paths organized
- Allow individual modules to be removed
- Reduce accidental disconnection

## High-Current and Signal Wiring

Motor and servo wires carry higher and rapidly changing currents.

Sensor and communication wires carry low-level signals.

Where practical, high-current wiring is kept separated from sensitive signal wiring to reduce electrical interference.

Long loose wire loops are avoided because they may:

- Enter the wheel path
- Pull on connectors
- Block the camera
- Vibrate in front of sensors
- Make fault diagnosis difficult

## Service Loops

Cables should not be stretched tightly.

A small controlled service loop allows a module to be disconnected or moved without placing force on the connector.

However, excess wire should remain secured.

---

# Thermal Considerations

Several modules may generate heat during operation, especially:

- Raspberry Pi
- L298N motor driver
- XL4015 converter
- MG996R servo under heavy load

The mechanical design should not completely enclose heat-generating components without ventilation.

During testing, the team should check:

- L298N temperature
- XL4015 temperature
- Servo temperature
- Raspberry Pi temperature
- Connector temperature
- Battery temperature

Unexpected heat may indicate:

- Excessive current
- Mechanical binding
- Incorrect voltage
- Poor converter adjustment
- Motor overload
- Loose or high-resistance connections

---

# Maintainability

The robot was designed so that common maintenance tasks do not require rebuilding the complete vehicle.

The modular structure allows:

- Removal of the Raspberry Pi case
- Access to the ESP32
- Replacement of a sensor
- Adjustment of the buck converter
- Removal of the motor driver
- Inspection of wiring
- Camera-angle adjustment
- Battery replacement

Each module should be identifiable by its location and cable path.

Clear file names, wiring documentation, and labeled photographs further reduce repair time during competition preparation.

---

# Mechanical Pre-Run Inspection

Before every test or official run, the following mechanical checks should be performed:

- Confirm that the vehicle remains within the allowed dimensions.
- Check that all wheels rotate freely.
- Check that the steering linkage moves without binding.
- Confirm that the servo horn is secure.
- Check wheel alignment.
- Check that the battery is fixed in position.
- Confirm that the Raspberry Pi case is secure.
- Check that the camera angle has not changed.
- Confirm that both ToF sensors are rigid.
- Check that the color sensor remains at the calibrated height.
- Inspect printed parts for cracks.
- Confirm that no cable touches a wheel.
- Confirm that no cable blocks a sensor.
- Check that screws have not loosened.
- Verify that the upper layer does not flex excessively.

Any change in mechanical configuration should be followed by recalibration because sensor position and weight distribution affect navigation behavior.
# 3D-Printed Parts

The robot uses a combination of:

1. Team-defined custom mechanical parts
2. Third-party downloadable models
3. Protective covers and electronic-module holders

The origin of each part is documented to clearly distinguish the team's engineering work from externally sourced designs.

This distinction is important because the team did not claim authorship of models downloaded from the internet.

---

# Custom Mechanical Parts

## Custom Third-Layer Assembly

The third-layer assembly was created specifically for this robot.

The design process began with physical measurements performed by the team.

The team measured:

- Chassis dimensions
- Available mounting area
- Hole locations
- Electronic-module dimensions
- Required cable clearances
- Wheel and steering clearances
- Maximum permitted robot dimensions
- Required access to connectors and switches

After defining these requirements, Zoo was used to generate the CAD geometry.

Therefore:

- The engineering requirements were defined by the team.
- The physical dimensions were measured by the team.
- The component arrangement was planned by the team.
- Zoo assisted with creating the digital CAD model.
- The resulting model was printed and physically tested by the team.

# Custom CAD Files

The custom third-layer CAD model is provided below together with the original manufacturing files used for 3D printing.

<p align="center">
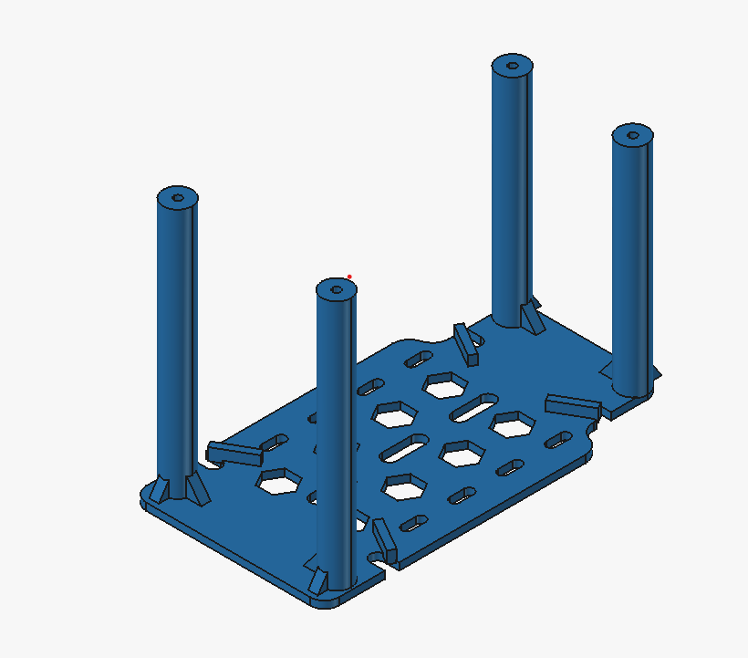
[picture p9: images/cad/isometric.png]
Custom Third Layer Isometric View
  
</p>

<p align="center">
  <em>Figure 1. Isometric view of the custom-designed third layer.</em>
</p>

## CAD Files

- [main.step](../cad/custom/main.step)

## STEP File

The STEP file preserves the editable three-dimensional geometry of the custom part. It allows future modifications, dimensional inspection, compatibility with CAD software, and manufacturing preparation.

## 3MF Files

The 3MF files are the printable versions of the custom part used during manufacturing. Depending on the slicing software, they may preserve model geometry, units, print orientation, object arrangement, and other print-related settings.

Both the editable CAD model and the printable files are included in the repository for documentation and reproducibility.

---

# Third-Party 3D Models

Several smaller holders and enclosures were downloaded from online repositories.

These parts were used because creating every standard electronic-module holder from the beginning would not provide significant engineering value compared with focusing effort on navigation, sensing, control, and the custom robot structure.

The downloaded models were reviewed for:

- Physical compatibility
- Component fit
- Mounting access
- Cable clearance
- Printability
- Mechanical rigidity
- Suitability for the available space

Where required, the installation method or surrounding robot layout was adapted to integrate these models.

---

# Raspberry Pi 3 Model B+ Case

The Raspberry Pi is protected using a third-party 3D-printable case.

## File Source

| Field | Information |
|---|---|
| Platform | Thingiverse |
| Designer | ZINN008 |
| Thing Number | 2786498 |
| License | Creative Commons Attribution |
| Purpose | Raspberry Pi 3 Model B+ enclosure |

## Reason for Use

The case provides:

- Mechanical protection
- Reduced risk of electrical contact
- Support for the Raspberry Pi board
- Easier mounting
- Improved cable organization
- Access to the required connectors

## Attribution

The original model was created by **ZINN008** and published on Thingiverse as **Thing 2786498** under a **Creative Commons Attribution license**.

The team does not claim authorship of this case.

---

# L298N Motor Driver Holder

The L298N module is installed using a downloaded 3D-printable holder.

## File

```text
L298N Holder ORP.stl
```

## Purpose

The holder provides:

- Mechanical retention
- Protection from movement
- Reduced connector stress
- Improved wiring organization
- Easier installation and removal

## Source

| Field | Information |
|---|---|
| Platform | Printables |
| Designer | ORP |
| Model Page | https://www.printables.com/model/832765-l298n-motor-driver-holder-orp |
| License | See the original Printables page |
| Local File | `L298N Holder ORP.stl` |

The original model was created by **ORP** and downloaded from **Printables**.

The team does not claim authorship of this holder.
---
# MPU6050 Enclosure

The MPU6050 is installed inside a downloaded protective enclosure.

## Files

TOP.3mf

Bottom.3mf

## Purpose

- Protects the MPU6050
- Keeps the sensor securely mounted
- Helps maintain consistent orientation
- Simplifies installation and maintenance
- 
## Source

| Field | Information |
|---|---|
| Platform | Printables |
| Model Page | https://www.printables.com/model/936662-mpu6050-case |
| License | See the original Printables page |
| Local Files | `TOP.3mf`, `Bottom.3mf` |

The original enclosure was downloaded from **Printables**.

The team does not claim authorship of this enclosure.

---

# XL4015 Buck Converter Enclosure

The XL4015 is installed inside a two-part downloaded enclosure.

## Files

```text
XL4015_Box_P1.3MF
XL4015_Box_P2_v2.3MF
```

## Purpose

The enclosure provides:

- Mechanical protection
- Reduced risk of accidental short circuits
- Stable mounting
- Improved wire routing
- Easier maintenance
- Physical separation from other electronic modules

The enclosure must not block airflow around the converter.

## Source

| Field | Information |
|---|---|
| Platform | Printables |
| Model Page | https://www.printables.com/model/253217-xl4015-buck-dc-to-dc-converter-box |
| License | See the original Printables page |
| Local Files | `XL4015_Box_P1.3MF`, `XL4015_Box_P2_v2.3MF` |

The original enclosure was downloaded from **Printables**.

The team does not claim authorship of this enclosure.

---

# TCS34725 Color Sensor Cover

A downloaded cover is used around the downward-facing TCS34725 color sensor.

## File

```text
TCS34725 cover light detection.stl
```

## Purpose

The cover helps:

- Reduce ambient-light interference
- Keep the sensor at a stable position
- Protect the sensor board
- Limit unwanted side lighting
- Improve measurement repeatability
- Maintain a consistent viewing area

The cover does not eliminate the need for software calibration.

Color thresholds must still be measured under actual track conditions.

## Source

| Field | Information |
|---|---|
| Platform | Printables |
| Model Page | https://www.printables.com/model/1148137-tcs34725-cover-light-detection |
| License | See the original Printables page |
| Local File | `TCS34725 cover light detection.stl` |

The original model was downloaded from **Printables**.

The team does not claim authorship of this cover.
---

# CAD Directory Organization

The CAD files should be organized so that judges and other teams can clearly identify which models were created for the robot and which were obtained from external sources.

A recommended directory structure is:

```text
cad/
├── custom/
│   └── main.step
│
├── raspberry_case/
├── l298n_holder/
├── xl4015_box/
├── mpu6050_enclosure/
└── tcs34725_cover/
```

This structure makes the distinction between custom and external work immediately visible.

---

# Recommended Attribution File

Each third-party model directory should include an `ATTRIBUTION.md` file.

Example:

```md
# Model Attribution

## Model Name

Raspberry Pi 3 Model B+ Case

## Original Creator

ZINN008

## Original Platform

Thingiverse

## Original Model Identifier

Thing 2786498

## License

Creative Commons Attribution

## Use in This Project

The model is used as a protective and mounting enclosure for the Raspberry Pi 3 Model B+.

## Modifications

State any modifications here.

If no modification was made, write:

No geometric modifications were made to the original model.
```

---

# Mechanical Integration Process

Every printed part was evaluated as part of the complete vehicle rather than as an isolated object.

The integration process included:

1. Checking the digital dimensions
2. Confirming print orientation
3. Printing the part
4. Testing component fit
5. Checking screw and connector access
6. Installing the part on the chassis
7. Checking wheel and steering clearance
8. Routing the cables
9. Verifying sensor visibility
10. Testing under vibration
11. Rechecking the overall robot dimensions
12. Updating the design or installation if required

A successful print was not considered complete until it operated correctly on the moving robot.

---

# 3D-Printing Design Considerations

## Tolerances

Printed dimensions may differ slightly from the CAD model because of:

- Printer calibration
- Material shrinkage
- Layer height
- Nozzle width
- Print orientation
- Hole geometry
- Slicer settings

Mounting holes and component openings must therefore include practical manufacturing tolerance.

## Wall Thickness

Printed parts must be thick enough to resist:

- Screw pressure
- Vibration
- Cable forces
- Repeated assembly
- Minor impacts

At the same time, unnecessary material should be avoided to reduce weight.

## Print Orientation

Print orientation affects:

- Strength
- Surface quality
- Support-material requirements
- Dimensional accuracy
- Screw-hole quality

Parts should be oriented so that the expected mechanical load does not easily separate the printed layers.

## Fasteners

Screws should be tightened enough to secure components, but not so tightly that they crack printed plastic or deform circuit boards.

Washers or spacers may be used where required to distribute force.

---

# Hardware Failure Modes and Mitigation

The following table summarizes common hardware risks and the corresponding mitigation strategy.

| Failure Mode | Possible Effect | Mitigation |
|---|---|---|
| Loose battery connection | Sudden power loss | Secure connector and inspect before each run |
| Battery movement | Changing balance or disconnected wires | Use a rigid battery holder or strong retention method |
| XL4015 incorrect output | Damage or unstable electronics | Measure output before connecting modules |
| Voltage drop during steering | ESP32 or Raspberry Pi reset | Use adequate power wiring and regulated supply |
| Servo mechanical binding | High current and poor steering | Calibrate safe steering limits |
| Loose servo horn | Incorrect wheel angle | Tighten and inspect the horn screw |
| Loose ToF sensor | Changing distance readings | Use a rigid mount and verify alignment |
| Blocked ToF field of view | Invalid wall readings | Keep wires and chassis edges outside the sensing path |
| Camera movement | Incorrect pillar position | Use a rigid adjustable mount |
| Color-sensor height change | Incorrect color classification | Secure the sensor and recalibrate after adjustment |
| Ambient light entering color sensor | Unstable RGB values | Use a cover and calibrated ratios |
| IMU vibration | Noisy angular measurements | Mount firmly on a rigid surface |
| L298N overheating | Reduced motor performance | Check load, ventilation, and motor current |
| Loose motor wires | Intermittent movement | Secure terminals and provide strain relief |
| Wire touching wheel | Mechanical failure | Route and secure all wires |
| Printed-part crack | Component movement | Inspect parts and reprint when damaged |
| Uncommon ground | Invalid signals or communication | Connect all required grounds together |
| Incorrect polarity | Component damage | Verify polarity before powering the robot |
| Raspberry Pi undervoltage | Vision instability | Use a stable supply and suitable wiring |
| Unbalanced component layout | Poor cornering behavior | Reposition heavy components where possible |

---

# Hardware Testing Strategy

Hardware testing is divided into subsystem tests and full-system tests.

Testing one subsystem at a time makes faults easier to identify.

## Power-System Test

The power system is tested by:

1. Disconnecting sensitive electronics.
2. Verifying battery polarity.
3. Measuring battery voltage.
4. Measuring XL4015 output voltage.
5. Connecting a controlled load.
6. Checking voltage stability.
7. Checking for excessive heating.
8. Connecting modules individually.
9. Observing voltage during servo movement.
10. Observing voltage during motor startup.

## Steering Test

The steering system is tested by:

1. Raising the front wheels from the surface.
2. Sending the center command.
3. Checking mechanical alignment.
4. Sending small left and right commands.
5. Checking for binding.
6. Finding the safe maximum limits.
7. Testing on the ground.
8. Rechecking current draw and servo temperature.

## Motor Test

The motor system is tested by:

1. Raising the driven wheels.
2. Testing low PWM values.
3. Confirming the forward direction.
4. Testing reverse separately.
5. Checking motor-driver temperature.
6. Testing under vehicle load.
7. Determining the lowest reliable movement command.
8. Checking speed consistency as battery voltage changes.

## ToF Sensor Test

Each ToF sensor is tested by:

1. Placing a flat target at known distances.
2. Recording repeated measurements.
3. Checking for invalid values.
4. Moving the target gradually.
5. Testing different wall materials.
6. Confirming the field of view.
7. Testing the mounted sensor while the motor is running.
8. Checking whether vibration affects the readings.

## IMU Test

The MPU6050 is tested by:

1. Keeping the robot stationary during startup.
2. Measuring the stationary gyroscope bias.
3. Rotating the robot by known approximate angles.
4. Checking axis direction.
5. Testing repeated left and right turns.
6. Observing drift over time.
7. Confirming that motor vibration does not dominate the measurement.

## Color-Sensor Test

The TCS34725 is tested by:

1. Recording values over normal track areas.
2. Recording values over orange markings.
3. Recording values over blue markings.
4. Repeating the test under different lighting.
5. Comparing raw values and normalized ratios.
6. Testing multiple sensor heights.
7. Selecting the most stable mounting height.
8. Confirming that the cover does not touch the floor.

## Camera Test

The camera system is tested by:

1. Checking the complete field of view.
2. Confirming that no wire blocks the image.
3. Checking focus and exposure.
4. Recording red and green pillar images.
5. Testing at different distances.
6. Testing under changing lighting.
7. Checking for vibration while driving.
8. Confirming that the mount returns to the same angle after maintenance.

---

# Full-System Hardware Test

After individual modules pass their tests, the complete vehicle is tested.

The full-system test checks:

- Startup reliability
- Power stability
- Motor and servo operation at the same time
- Sensor stability during movement
- Camera processing during vehicle motion
- Communication between controllers
- Mechanical vibration
- Thermal performance
- Cable retention
- Repeatability across multiple runs

A successful single run is not considered sufficient.

The same test should be repeated several times to identify intermittent faults.

---

# Hardware Maintenance Schedule

## Before Every Run

- Inspect battery condition
- Confirm battery retention
- Check power-switch operation
- Check all connectors
- Check wheel movement
- Check steering-center position
- Inspect sensor mounts
- Confirm camera angle
- Check cables near wheels
- Check printed parts
- Measure the robot dimensions when the configuration changes

## After Every Test Session

- Disconnect the battery
- Check module temperatures
- Inspect the motor driver
- Inspect the buck converter
- Check servo temperature
- Review loose wires
- Clean sensor windows
- Inspect the camera lens
- Record any mechanical change

## Periodically

- Tighten screws
- Check wheel alignment
- Check steering-linkage play
- Inspect solder joints
- Test the battery under load
- Recheck converter output
- Recalibrate sensors
- Replace damaged printed parts
- Update wiring photographs
- Update the hardware documentation

---

# Hardware Change Control

Any hardware modification can affect software behavior.

Examples include:

- Moving a ToF sensor
- Changing the camera angle
- Changing the color-sensor height
- Replacing the servo horn
- Moving the battery
- Changing wheel diameter
- Modifying the upper layer
- Changing the motor driver
- Changing the regulated voltage

For this reason, every significant hardware modification should be recorded in the engineering journal.

The record should include:

- Date
- Modified component
- Reason for change
- Previous configuration
- New configuration
- Expected effect
- Test result
- Required recalibration

This prevents software tuning from being evaluated using an undocumented mechanical configuration.

---

# Hardware Limitations

The current hardware design has several known limitations.

## L298N Efficiency

The L298N introduces a noticeable voltage drop and produces more heat than a modern MOSFET-based motor driver.

A future design could use a more efficient motor driver to improve:

- Motor voltage
- Battery usage
- Thermal performance
- Low-speed control

## Raspberry Pi Boot Time

The Raspberry Pi requires more startup time than the ESP32.

The robot software must ensure that the vehicle does not begin a vision-dependent run before the Raspberry Pi is ready.

## Servo Power Demand

The MG996R can create large current changes.

The power system must remain stable during fast steering actions.

## Sensor Dependence on Mounting

The ToF sensors, camera, IMU, and color sensor all depend strongly on their mounting positions.

A small mechanical change may require software recalibration.

## Raised Center of Gravity

The additional upper layer increases the center of gravity.

This is reduced by keeping heavy components low, but it cannot be completely eliminated.

## Commercial Chassis Constraints

The commercial chassis limits:

- Wheelbase adjustment
- Track-width adjustment
- Steering geometry
- Motor placement
- Available mounting space

The custom layer improves integration but does not remove all platform constraints.

---

# Future Hardware Improvements

Possible future improvements include:

- Replacing the L298N with a more efficient MOSFET motor driver
- Designing a completely custom electronics carrier
- Reducing unnecessary printed material
- Lowering the upper-layer mass
- Adding dedicated locking connectors
- Improving strain relief
- Creating indexed sensor mounts with repeatable angles
- Adding test points for important voltages
- Adding current measurement
- Adding battery-voltage monitoring
- Improving cooling around the Raspberry Pi
- Adding a custom power-distribution board
- Integrating fuses or additional electrical protection
- Improving wheel-alignment adjustment
- Creating a modular quick-release battery holder

These are improvement opportunities rather than claims about the current robot.

---

# Hardware Documentation Evidence

The repository should include clear photographs showing:

- Complete robot from the front
- Complete robot from the rear
- Left side
- Right side
- Top view
- Bottom view
- Battery location
- Main power switch
- ESP32 installation
- Raspberry Pi installation
- Camera mounting
- Both ToF sensor positions
- MPU6050 position
- TCS34725 position
- Servo and steering linkage
- Motor and drivetrain
- L298N installation
- XL4015 installation
- Custom third layer
- Cable routing
- Robot dimensions

Photographs should use arrows or labels where needed.

Example image structure:

```text
images/
├── hardware/
│   ├── robot-front.jpg
│   ├── robot-rear.jpg
│   ├── robot-left.jpg
│   ├── robot-right.jpg
│   ├── robot-top.jpg
│   ├── robot-bottom.jpg
│   ├── esp32-location.jpg
│   ├── raspberry-pi-location.jpg
│   ├── camera-mount.jpg
│   ├── tof-left.jpg
│   ├── tof-right.jpg
│   ├── imu-location.jpg
│   ├── color-sensor-location.jpg
│   ├── servo-linkage.jpg
│   ├── motor-driver.jpg
│   ├── buck-converter.jpg
│   ├── battery-mount.jpg
│   ├── third-layer.jpg
│   └── cable-routing.jpg
│
└── dimensions/
    ├── robot-length.jpg
    ├── robot-width.jpg
    └── robot-height.jpg
```

---

# Final Hardware Summary

The robot hardware combines a commercial Ackermann chassis with a custom layered electronics structure.

The architecture separates real-time vehicle control from computer-vision processing:

- The ESP32 manages sensors, steering, motor control, and navigation logic.
- The Raspberry Pi performs camera-based object detection.
- Two VL53L1X sensors measure surrounding distances.
- The MPU6050 provides inertial information.
- The TCS34725 detects colored floor markings.
- The MG996R controls the front steering mechanism.
- The geared DC motor provides propulsion through the L298N driver.
- The XL4015 regulates power for the electronic systems.
- A 2S lithium-ion battery supplies the robot.
- Custom and third-party 3D-printed parts organize and protect the hardware.

The custom third layer was developed from measurements and requirements defined by the team, with Zoo used to generate the digital model.

Downloaded parts are documented separately and are not presented as original team designs.

The resulting platform prioritizes:

- Reliability
- Modularity
- Sensor stability
- Maintainability
- Organized wiring
- Safe power distribution
- Competition-size compliance
- Future expandability

The hardware design is not treated as a fixed final product.

It is treated as an engineering platform that is continuously tested, measured, documented, and improved.

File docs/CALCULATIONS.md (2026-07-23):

# Engineering Calculations

## Purpose

This document presents the engineering calculations and quantitative analysis used during the design and development of our WRO Future Engineers 2026 robot.

Rather than selecting components through trial and error, mathematical calculations and engineering measurements were used to justify design decisions, evaluate system performance, and estimate the robot's capabilities before practical testing.

Whenever possible, theoretical calculations were compared with experimental observations to verify the accuracy of the design.

---

# 1. Robot Dimensions

The robot dimensions were measured after the mechanical assembly was completed.

| Parameter | Value |
|---|---|
| Length | 248 mm |
| Width | 146 mm |
| Height | 70 mm |

These measurements confirm that the robot complies with the dimensional constraints of the WRO Future Engineers competition.

---

# 2. Robot Weight

Measured robot weight (without battery and camera):

**599 g**

The measured value currently excludes:

- Battery
- Raspberry Pi Camera

The complete robot weight will be updated after the final competition configuration is assembled.

Robot weight directly influences acceleration, braking performance, motor load, and overall power consumption.

---

# 3. Wheel Dimensions

Drive wheel diameter:

**65 mm**

Accurate wheel measurements are essential because they influence vehicle speed estimation, turning behaviour, and encoder-free distance calculations.

---

# 4. Wheel Circumference

The wheel circumference was calculated using:

Wheel Circumference = π × Diameter

= 3.1416 × 65

= **204.2 mm**

This value represents the theoretical distance travelled during one complete wheel revolution.

---

# 5. Gear Ratio Analysis

The gearbox manufacturer did not specify the internal reduction ratio.

To determine the actual transmission ratio, the gearbox was completely disassembled and every gear was inspected manually.

The number of teeth on every gear was counted individually.

| Stage | Calculation | Ratio |
|---|---|---:|
| Stage 1 | 22 / 12 | 1.83 |
| Stage 2 | 20 / 12 | 1.67 |
| Stage 3 | 22 / 10 | 2.20 |
| Stage 4 | 23 / 10 | 2.30 |

Overall Gear Ratio

= (22/12) × (20/12) × (22/10) × (23/10)

= **15.46 : 1**

### Gearbox Inspection

The gearbox was carefully disassembled to verify the reduction ratio manually.

Every gear stage was inspected before calculating the final reduction ratio.

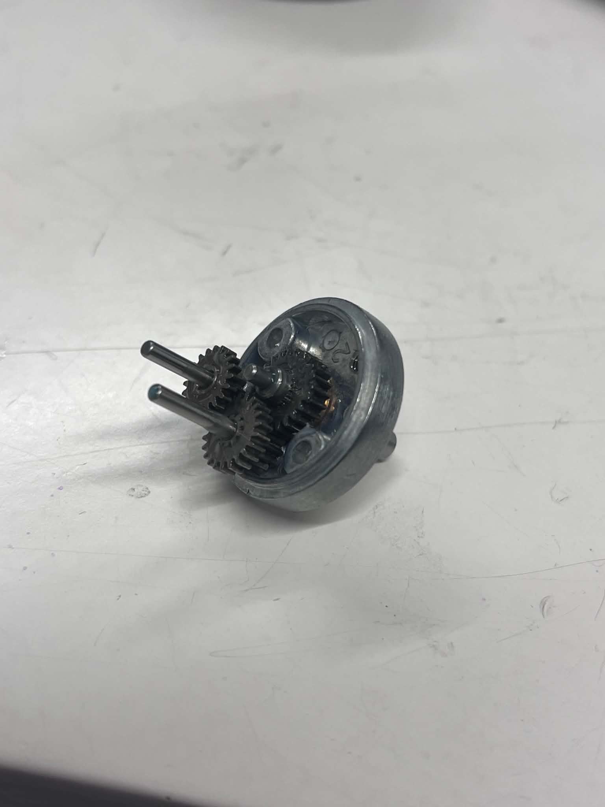
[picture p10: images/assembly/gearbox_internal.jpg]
Gearbox Inspection


**Figure 1.** Manual gearbox inspection during reduction ratio calculation.

---

# 6. Theoretical Wheel Speed

The theoretical wheel rotational speed can be estimated using:

Wheel RPM = Motor RPM / Gear Ratio

Using the measured gearbox ratio:

Wheel RPM = Motor RPM / 15.46

The final numerical value depends on the motor speed at the actual operating voltage.

---

# 7. Theoretical Vehicle Speed

The theoretical vehicle speed is estimated using the wheel circumference and wheel rotational speed.

Vehicle Speed = Wheel Circumference × Wheel RPM

or

Vehicle Speed (m/s)

= (204.2 × Wheel RPM) / 60000

The calculated value represents the ideal speed before considering wheel slip, drivetrain losses, battery voltage drop, and mechanical friction.

Actual performance is expected to be slightly lower.

---

# 8. Experimental Performance Measurements

Practical testing is used to validate the theoretical calculations.

The robot is tested by driving a known distance while measuring the travel time.

Vehicle Speed = Distance / Time

Multiple experimental runs are performed to evaluate repeatability and reduce measurement uncertainty.

Future measurements will include:

- Average vehicle speed
- Maximum vehicle speed
- Lap consistency
- Speed variation during turning

---

# 9. Steering Evaluation

Because the robot uses an Ackermann steering system, steering geometry plays an important role in navigation accuracy.

During testing, steering behaviour is evaluated by observing:

- Turning consistency
- Turning position
- Turning smoothness
- Repeatability over multiple laps

Practical testing is used to determine the steering parameters that produce the most reliable autonomous navigation.

---

# 10. Power System Analysis

Electrical power requirements are evaluated after integrating the complete robot.

The electrical power consumed by each subsystem is determined using:

Power = Voltage × Current

Future measurements will include:

| Component | Voltage | Current | Power |
|---|---|---|---|
| ESP32 | To be measured | To be measured | To be calculated |
| Raspberry Pi 3 Model B | To be measured | To be measured | To be calculated |
| Drive Motor | To be measured | To be measured | To be calculated |
| Steering Servo | To be measured | To be measured | To be calculated |
| Sensors | To be measured | To be measured | To be calculated |

The total system power will be calculated by summing the power consumption of all subsystems.

---

# 11. Battery Runtime Estimation

The expected operating time is estimated using:

Runtime (hours)

= Battery Capacity (Ah)

÷ Average Current (A)

The theoretical value will be compared with the actual runtime measured during continuous autonomous operation.

---

# 12. Engineering Observations

Engineering calculations were not performed only for documentation purposes.

They directly influenced several design decisions throughout the project, including:

- Selecting the drivetrain configuration.
- Understanding gearbox performance.
- Estimating theoretical vehicle speed.
- Planning battery requirements.
- Evaluating steering performance.
- Comparing theoretical predictions with practical testing.

These calculations provided quantitative support for many engineering decisions made during the development of the robot.

---

# Future Updates

This document will continue to evolve as additional measurements become available during future testing.

Planned additions include:

- Final robot weight
- Experimental vehicle speed
- Battery runtime measurements
- Current consumption measurements
- Power consumption analysis
- Steering geometry measurements
- Turning radius evaluation
- Long-term performance measurements

Continuous measurement and validation remain an essential part of the engineering development process.

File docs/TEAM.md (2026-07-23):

# Team

<p align="center">

</p>

---

# NextGen Minds

We are **NextGen Minds**, a team of second-year Computer Engineering students from Birzeit University representing Palestine in the World Robot Olympiad (WRO) Future Engineers 2026.

Our team combines embedded systems, computer vision, and software engineering to design and build an autonomous Ackermann steering vehicle capable of completing the WRO challenges.

---

# Team Members

| Batool Ghanem | Sara Abuarra |
|:---:|:---:|
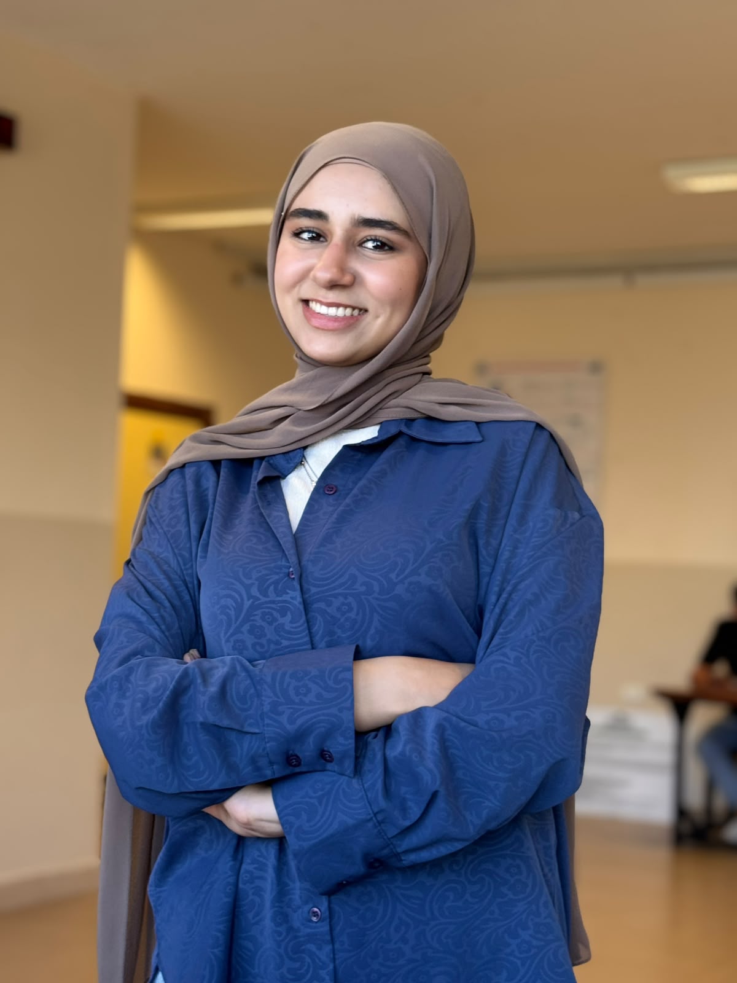
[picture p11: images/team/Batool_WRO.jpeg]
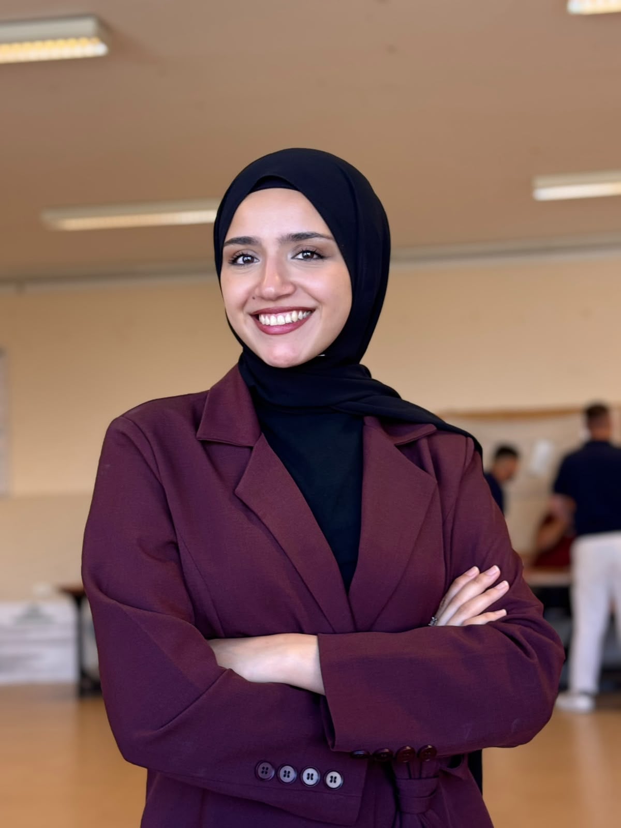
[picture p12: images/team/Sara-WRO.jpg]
|  |  |
| **Computer Vision**<br>Raspberry Pi Software<br>Documentation | **Embedded Systems**<br>ESP32 Firmware<br>Electronics Integration |

---

# Coach

**Osid Ali**

---

# Institution

Birzeit University

---

# Country

Palestine 🇵🇸

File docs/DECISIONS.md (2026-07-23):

# Engineering Decisions

## Introduction

Every major decision in this project was made after comparing multiple alternatives instead of selecting components based on popularity or personal preference.

For each important subsystem, we identified the engineering requirements, evaluated the available options, discussed their advantages and disadvantages, and finally selected the solution that best matched the objectives of our robot.

This document explains the reasoning behind every important engineering decision made during the project.

---

# Decision 1 – System Controller Selection

## Engineering Problem

The robot must process camera images, detect lanes and walls, recognize colors, control steering, drive the motor, read multiple sensors, and make navigation decisions in real time.

Using a single controller for all these tasks could reduce performance, increase software complexity, and make debugging more difficult.

---

## Engineering Requirements

The controller architecture should:

- Support computer vision.
- Provide reliable real-time control.
- Be easy to debug.
- Allow future expansion.
- Support communication between software modules.
- Keep the software modular.

---

## Alternatives Evaluated

| Controller | Advantages | Disadvantages |
|---|---|---|
| Arduino Uno | Very simple, inexpensive, huge community support | Insufficient RAM and processing power for computer vision and multiple concurrent tasks |
| Arduino Mega | More I/O pins than Uno, simple programming | Still not suitable for OpenCV or image processing |
| ESP32 | Excellent real-time performance, Wi-Fi, Bluetooth, low power consumption | Cannot efficiently perform computer vision |
| Raspberry Pi 3B | Powerful processor, Linux operating system, OpenCV support, USB and CSI camera support | Real-time motor control is less deterministic under heavy CPU load |
| Raspberry Pi 3B + ESP32 | Combines powerful image processing with reliable real-time control | Slightly more complex hardware and software architecture |

---

## Final Decision

Our robot uses both a Raspberry Pi 3B and an ESP32.

The Raspberry Pi is responsible for all high-level processing tasks including:

- Camera image acquisition
- Lane detection
- Wall detection
- Color recognition
- Navigation logic
- Decision making

The ESP32 is responsible for all low-level control tasks including:

- Steering servo control
- DC motor control
- Reading sensors
- Executing movement commands
- Safety functions

Communication between both controllers is performed using UART serial communication.

---

## Why We Selected This Architecture

Separating computer vision from low-level motor control improves system reliability and software organization.

The Raspberry Pi can dedicate all processing power to image analysis while the ESP32 guarantees stable real-time control regardless of processor load.

This architecture also simplifies debugging and future upgrades because each controller has a clearly defined responsibility.

---

## Trade-offs

Advantages

- Excellent modularity
- Better real-time performance
- Easier debugging
- Better scalability
- Improved software organization

Disadvantages

- Two controllers instead of one
- Additional UART communication required
- Slightly more complex software architecture

---

# Decision 2 – Power System Selection

## Engineering Problem

The robot requires a stable power system capable of supplying multiple electronic devices with different voltage and current requirements.

The Raspberry Pi, ESP32, sensors, servo motor, and DC motor cannot all operate directly from the same voltage without proper power regulation.

Therefore, a reliable and efficient power distribution system was required.

---

## Engineering Requirements

The power system should:

- Provide stable power for all electronic components.
- Supply sufficient current during peak loads.
- Support long testing sessions.
- Be lightweight.
- Be easy to recharge.
- Minimize voltage drop.
- Improve overall system reliability.

---

## Alternatives Evaluated

| Power Source | Advantages | Disadvantages |
|---|---|---|
| 9V Alkaline Battery | Low cost, widely available | Very low current capability, unsuitable for motors and Raspberry Pi |
| 18650 Li-ion (2S) | Rechargeable, lightweight, high energy density, easy to replace | Requires protection circuit and charger |
| LiPo Battery (2S) | High discharge current, lightweight, widely used in robotics | Requires careful charging and handling |

---

## Battery Selection

After evaluating the available options, we selected a **2S Lithium-Ion battery pack (7.4V)**.

This configuration provides sufficient voltage for the motor while allowing the remaining electronics to be powered through a voltage regulator.

The selected battery also provides a good balance between runtime, weight, cost, and availability.

---

## Voltage Regulation

Different components require different supply voltages.

The DC motor operates from the battery voltage through the motor driver.

The Raspberry Pi, ESP32, camera, and sensors require a stable 5V supply.

For this reason, a DC-DC Buck Converter is used to convert the battery voltage into a regulated 5V output.

---

## Alternatives for Voltage Regulation

| Converter | Advantages | Disadvantages |
|---|---|---|
| Linear Voltage Regulator | Simple design | Low efficiency, high heat generation |
| Boost Converter | Useful when increasing voltage | Cannot reduce battery voltage |
| DC-DC Buck Converter | High efficiency, low heat, stable output | Slightly higher cost |

---

## Final Decision

The robot will use:

- 2S 7.4V Lithium-Ion Battery
- DC-DC Buck Converter for regulated 5V
- Shared common ground between all controllers

This configuration provides stable operation while reducing power losses and improving reliability.

---

## Trade-offs

Advantages

- High efficiency
- Stable power distribution
- Long runtime
- Rechargeable
- Suitable for future expansion

Disadvantages

- Additional converter required
- Slightly more complex wiring
- ---

# Decision 3 – Motor Driver Selection

## Engineering Problem

The DC motor requires a dedicated driver capable of controlling both speed and direction while safely handling the motor current.

The motor driver must also interface easily with the ESP32 and operate reliably throughout long testing sessions.

---

## Engineering Requirements

The motor driver should:

- Support bidirectional motor control.
- Operate from the selected battery voltage.
- Be compatible with ESP32 logic levels.
- Provide stable operation.
- Be easy to replace if future upgrades become necessary.
- Have sufficient current capability.

---

## Alternatives Evaluated

| Driver | Advantages | Disadvantages |
|---|---|---|
| L9110S | Small, inexpensive, simple wiring | Low current capability, unsuitable for larger DC motors |
| TB6612FNG | High efficiency, low voltage drop, compact size | Slightly more expensive and less available locally |
| BTS7960 | Very high current capability, excellent efficiency | Larger than required for our current motor |
| L298N | Widely available, inexpensive, simple to use, well documented | Lower efficiency and noticeable voltage drop |

---

## Final Decision

The current prototype uses the **L298N motor driver**.

The main reasons for selecting this driver were its availability, ease of integration, extensive documentation, and compatibility with our motor and battery configuration.

Although newer drivers provide higher efficiency, the L298N was considered sufficient during the development stage and allowed rapid hardware integration and software testing.

---

## Future Improvements

Future versions of the robot may replace the L298N with a more efficient motor driver such as the TB6612FNG.

This would reduce voltage loss, improve motor efficiency, decrease heat generation, and increase the available voltage at the motor terminals.

---

## Trade-offs

Advantages

- Easy to obtain.
- Simple software interface.
- Large amount of educational documentation.
- Reliable during development.

Disadvantages

- Higher voltage drop than modern MOSFET drivers.
- Lower electrical efficiency.
- Generates more heat under higher loads.
- ---

# Decision 4 – Steering Servo Selection

## Engineering Problem

The steering system requires a servo motor capable of accurately controlling the front wheels while overcoming the steering resistance generated by the tires and steering mechanism.

A weak servo could result in inaccurate steering, slow response, or failure to reach the required steering angle.

---

## Engineering Requirements

The steering servo should:

- Provide sufficient torque.
- Have good positioning accuracy.
- Be mechanically reliable.
- Support standard PWM control.
- Operate continuously during long testing sessions.
- Be compatible with the ESP32.

---

## Alternatives Evaluated

| Servo | Advantages | Disadvantages |
|---|---|---|
| SG90 | Small, inexpensive, low power consumption | Very low torque, plastic gears, unsuitable for steering |
| MG90S | Metal gears, better precision than SG90 | Torque still limited for our steering mechanism |
| DS3218 | Very high torque, waterproof versions available | Larger size, heavier, more expensive |
| MG996R | High torque, metal gears, reliable, widely available | Higher current consumption and larger size |

---

## Final Decision

The MG996R servo was selected because it provides sufficient torque to steer the vehicle reliably while maintaining accurate steering control.

Its metal gear construction improves durability compared to smaller plastic gear servos, making it more suitable for repeated testing and competition use.

---

## Why We Selected This Servo

The steering mechanism transfers significant mechanical load to the servo during turning.

Selecting a high-torque servo reduces steering errors, improves repeatability, and increases the reliability of autonomous navigation.

Although the MG996R consumes more current than smaller servos, the additional torque provides a significant improvement in steering performance.

---

## Trade-offs

Advantages

- High torque
- Metal gears
- Reliable operation
- Excellent availability
- Easy PWM control

Disadvantages

- Higher current consumption
- Heavier than micro servos
- Larger physical dimensions
- ---

# Decision 5 – DC Motor Selection

## Engineering Problem

The robot requires a DC gear motor capable of moving the vehicle smoothly while providing sufficient torque for acceleration, turning, and obstacle avoidance.

The selected motor should maintain stable performance throughout the competition without excessive power consumption.

---

## Engineering Requirements

The motor should:

- Produce sufficient torque.
- Maintain stable speed.
- Fit inside the chassis.
- Be mechanically reliable.
- Operate from the selected battery.
- Be compatible with the selected motor driver.
- Support long operating periods.

---

## Alternatives Evaluated

| Motor | Advantages | Disadvantages |
|---|---|---|
| TT Gear Motor | Very inexpensive, easy to obtain | Plastic gearbox, lower precision, lower durability |
| N20 Gear Motor | Compact size, good precision | Lower torque for this chassis |
| RS380 Motor | Higher speed, larger power | Larger size, requires different mounting system |
| JGA25-370 Gear Motor | Metal gearbox, compact design, suitable torque, reliable performance | Slightly heavier than smaller motors |

---

## Final Decision

The JGA25-370 geared DC motor was selected because it provides a good balance between torque, size, efficiency, reliability, and compatibility with the selected chassis.

Its integrated metal gearbox produces sufficient torque for autonomous navigation while maintaining a compact mechanical design.

The selected motor also fits directly into the chassis without requiring additional mechanical modifications.

---

## Engineering Justification

The project requires accurate low-speed movement rather than maximum speed.

A geared motor provides higher torque at lower wheel speeds, improving vehicle stability during steering, obstacle avoidance, and cornering.

The gearbox reduction ratio also reduces the mechanical load on the motor, improving efficiency and controllability.

---

## Trade-offs

Advantages

- High torque
- Metal gearbox
- Compact construction
- Reliable operation
- Easy installation
- Good compatibility with the chassis

Disadvantages

- Lower maximum speed than direct-drive motors
- Slightly higher weight
- Gearbox introduces small mechanical losses

- ---

# Decision 6 – Camera Selection

## Engineering Problem

The robot relies on computer vision to detect lanes, walls, colored objects, and obstacles.

The selected camera must provide reliable image quality while maintaining low latency to support real-time autonomous navigation.

---

## Engineering Requirements

The camera should:

- Be compatible with the Raspberry Pi.
- Produce stable image quality.
- Support OpenCV.
- Operate with low latency.
- Be lightweight.
- Be mechanically easy to mount.
- Consume low power.

---

## Alternatives Evaluated

| Camera | Advantages | Disadvantages |
|---|---|---|
| USB Webcam | Easy to connect, inexpensive, widely available | Higher latency, larger size, increased USB bandwidth usage |
| Smartphone Camera | Excellent image quality | Difficult integration, unstable connection, unsuitable for autonomous robotics |
| Raspberry Pi Camera Module | Native CSI interface, low latency, compact size, excellent OpenCV compatibility | Slightly higher cost than entry-level USB cameras |

---

## Final Decision

The Raspberry Pi Camera Module was selected because it communicates directly through the Raspberry Pi CSI interface.

This provides lower latency, higher stability, and better integration with OpenCV compared to standard USB webcams.

The compact size also simplifies mechanical installation while reducing additional cable management.

---

## Engineering Justification

Computer vision is the most important sensing system in our robot.

Reducing image latency improves steering response, lane detection accuracy, and overall navigation performance.

The Raspberry Pi Camera Module provides direct hardware integration with the Raspberry Pi, allowing image acquisition without unnecessary USB communication overhead.

---

## Trade-offs

Advantages

- Low latency
- Compact design
- Excellent Raspberry Pi compatibility
- Reliable OpenCV support
- Low power consumption

Disadvantages

- Requires CSI ribbon cable
- Dedicated to Raspberry Pi systems
- ---

# Decision 7 – Distance Sensor Selection

## Engineering Problem

The robot requires reliable distance measurements to detect walls, maintain a safe distance, and assist autonomous navigation during the competition.

The selected sensor should provide accurate measurements while remaining compact and easy to integrate into the robot.

---

## Engineering Requirements

The distance sensor should:

- Provide accurate distance measurements.
- Have fast response time.
- Be compact.
- Consume low power.
- Be compatible with the ESP32.
- Operate reliably indoors.
- Support continuous measurements.

---

## Alternatives Evaluated

| Sensor | Advantages | Disadvantages |
|---|---|---|
| HC-SR04 Ultrasonic | Very inexpensive, easy to use, widely available | Lower accuracy, wider detection angle, affected by surface reflections |
| Sharp IR Distance Sensor | Simple interface, compact size | Lower accuracy at longer distances, affected by object color |
| VL53L1X Time-of-Flight | Laser-based measurement, high accuracy, compact size, fast response | Default I²C address conflict when multiple sensors are connected |

---

## Final Decision

The VL53L1X Time-of-Flight sensor was selected because it provides significantly higher accuracy and faster response than traditional ultrasonic sensors.

Its compact size and laser-based distance measurement make it well suited for precise wall detection during autonomous driving.

---

## Engineering Justification

Reliable wall detection is essential for maintaining vehicle position and avoiding collisions.

Compared to ultrasonic sensors, the VL53L1X offers more stable measurements and is less affected by surrounding objects or irregular wall surfaces.

This improves navigation accuracy during the competition.

---

## Engineering Challenges

During development, both VL53L1X sensors initially shared the same default I²C address.

This prevented both sensors from operating simultaneously on the same I²C bus.

Several software solutions were investigated, including changing the sensor address during startup.

Although one sensor operated correctly, additional debugging was required before both sensors could be used simultaneously.

This challenge and the attempted solutions were documented as part of the engineering development process.

---

## Trade-offs

Advantages

- High measurement accuracy
- Fast response time
- Compact design
- Low power consumption
- Excellent wall detection performance

Disadvantages

- I²C address conflict when using multiple sensors
- More complex software initialization than ultrasonic sensors

- ---

# Decision 8 – Color Sensor Selection

## Engineering Problem

The robot must reliably identify colored objects and field markers under different lighting conditions.

The selected sensor should provide stable color measurements while minimizing the influence of ambient light.

---

## Engineering Requirements

The color sensor should:

- Detect colors accurately.
- Operate under different lighting conditions.
- Be compact and lightweight.
- Be compatible with the ESP32.
- Consume low power.
- Provide stable measurements.
- Be easy to calibrate.

---

## Alternatives Evaluated

| Sensor | Advantages | Disadvantages |
|---|---|---|
| TCRT5000 | Very inexpensive, simple interface | Suitable only for line detection, cannot accurately distinguish colors |
| Camera-Based Color Detection | High flexibility, detects multiple colors simultaneously | Higher computational load and affected by lighting conditions |
| TCS34725 Color Sensor | Dedicated RGB sensor, integrated white LED, high accuracy, I²C communication | Requires calibration for different lighting environments |

---

## Final Decision

The TCS34725 color sensor was selected because it provides reliable RGB color measurements while remaining compact and easy to integrate with the ESP32.

Its dedicated color sensing hardware allows accurate color recognition without increasing the computational load on the Raspberry Pi.

---

## Engineering Justification

Separating color detection from computer vision reduces the processing workload on the Raspberry Pi and allows color measurements to be performed independently.

This improves software modularity and enables the Raspberry Pi to dedicate more processing power to lane detection, wall detection, and navigation.

---

## Trade-offs

Advantages

- Accurate RGB measurements
- Compact design
- Low power consumption
- Easy integration with ESP32
- Fast measurements

Disadvantages

- Requires calibration under different lighting conditions
- I²C communication requires correct bus configuration

- ---

# Decision 9 – Battery Selection

## Engineering Problem

The robot requires a lightweight and rechargeable power source capable of supplying stable voltage and sufficient current for all electronic components during the competition.

---

## Engineering Requirements

The battery should:

- Supply enough current for the motor and electronics.
- Provide stable voltage.
- Be rechargeable.
- Have good energy density.
- Be lightweight.
- Support long operating time.

---

## Alternatives Evaluated

| Battery | Advantages | Disadvantages |
|---|---|---|
| 9V Alkaline Battery | Cheap and easy to find | Very low current capability, unsuitable for robotics |
| LiPo 2S | High discharge current, lightweight | Requires careful charging and storage |
| 18650 Li-ion (2S) | Rechargeable, high capacity, widely available, safer handling | Requires battery management and protection |

---

## Final Decision

A 2S Lithium-Ion battery pack was selected because it provides an excellent balance between capacity, weight, operating time, safety, and cost.

The battery voltage is suitable for the drive motor while a DC-DC Buck Converter provides a regulated 5V supply for the Raspberry Pi, ESP32, camera, and sensors.

---

## Trade-offs

Advantages

- Rechargeable
- Lightweight
- High capacity
- Stable output voltage
- Good operating time

Disadvantages

- Requires a charging circuit
- Requires battery protection

- ---

# Decision 10 – Chassis Selection

## Engineering Problem

The robot requires a rigid chassis capable of supporting all mechanical and electronic components while maintaining accurate steering and stable vehicle dynamics.

---

## Engineering Requirements

The chassis should:

- Be mechanically rigid.
- Support rear-wheel drive.
- Provide accurate steering.
- Be lightweight.
- Allow easy maintenance.
- Provide enough space for electronics.

---
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

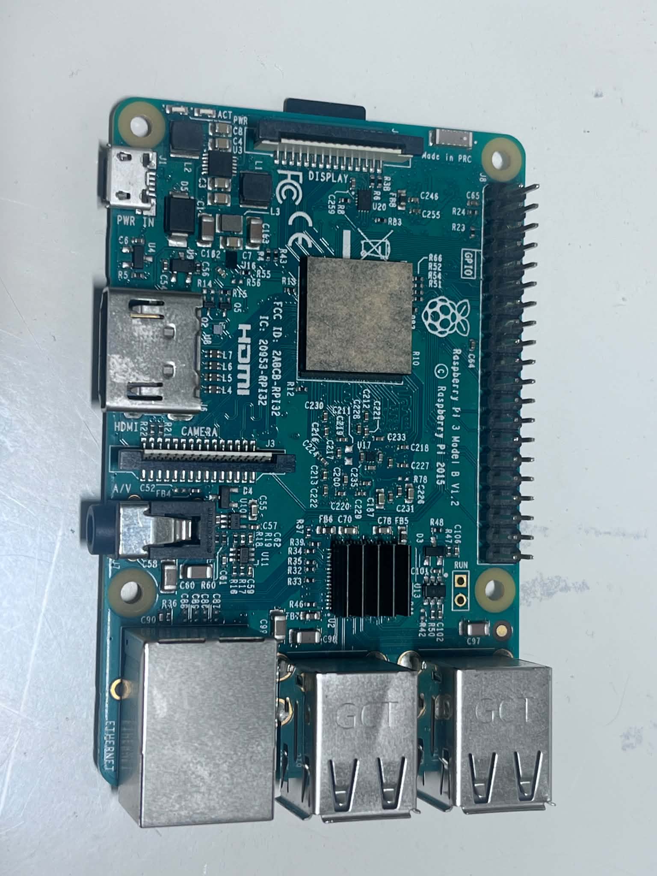
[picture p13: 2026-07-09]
images/hardware/Raspberry_pi3_modelB.jpg

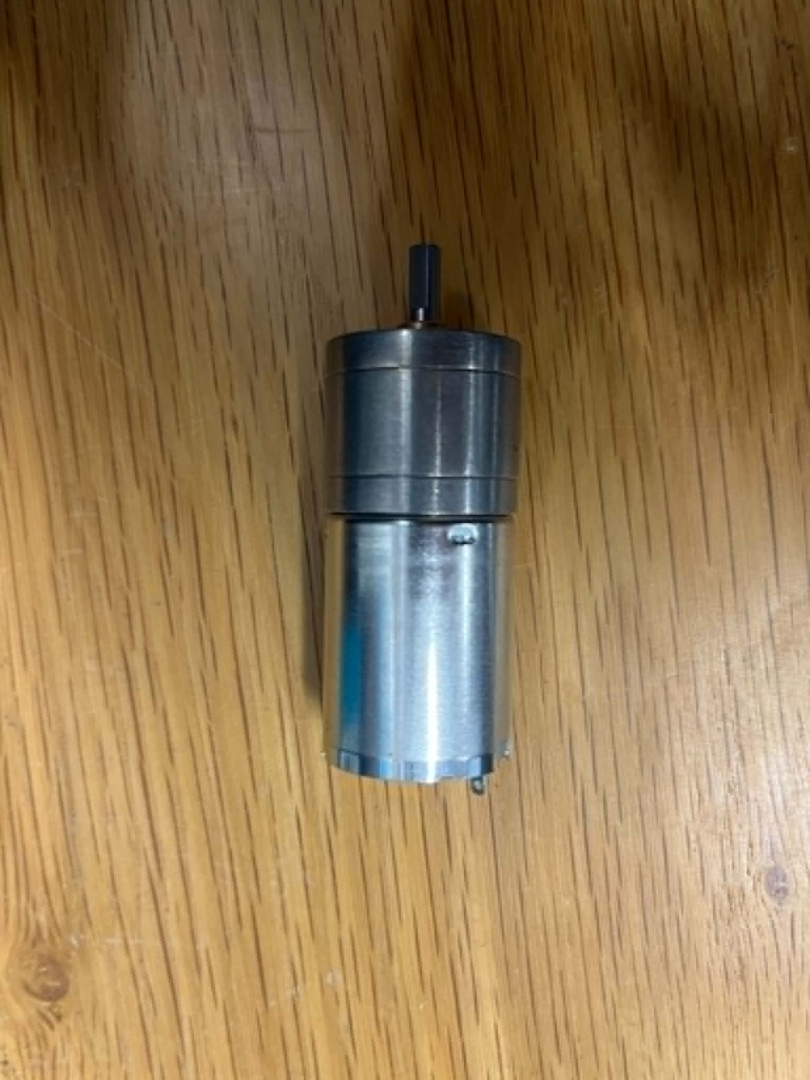
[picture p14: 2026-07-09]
images/hardware/dc_motor.jpg

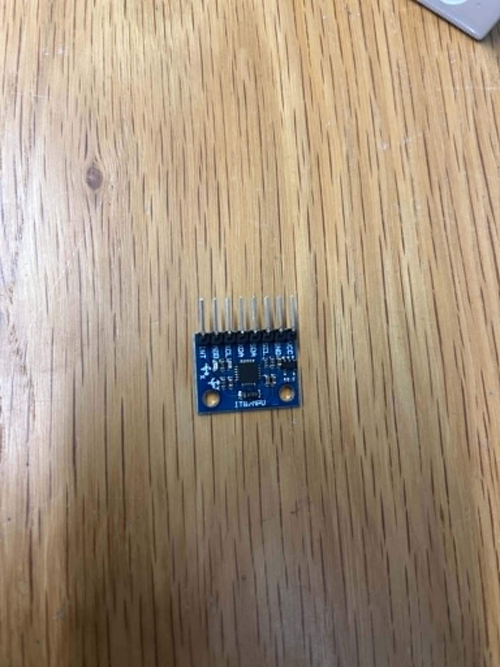
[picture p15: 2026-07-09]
images/hardware/mpu6050.jpg

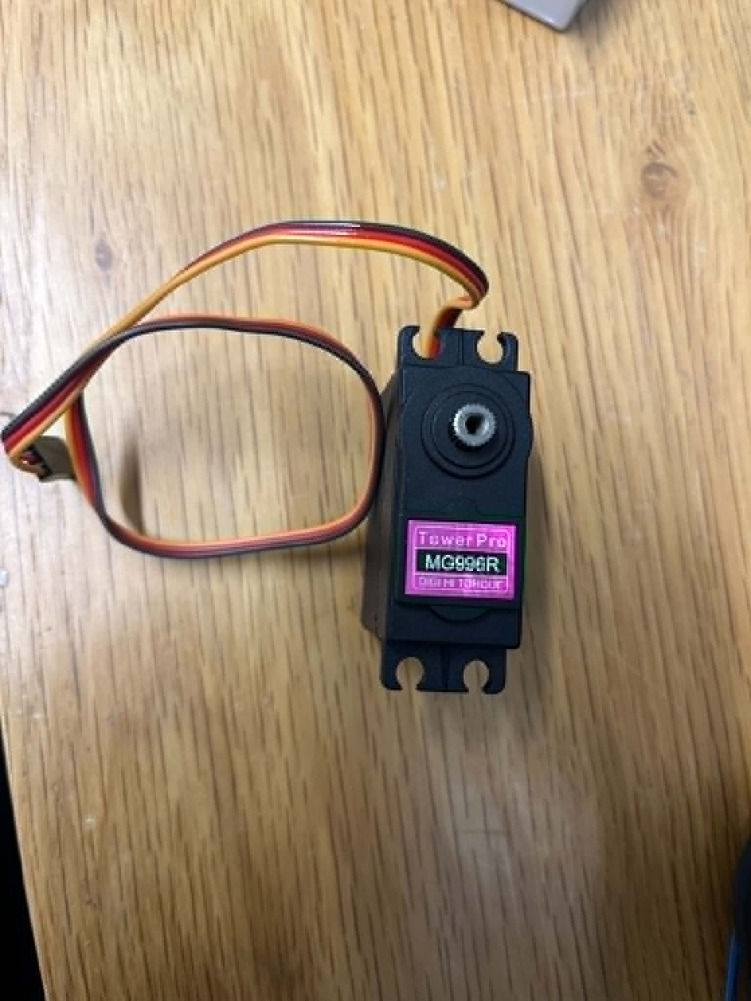
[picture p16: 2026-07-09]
images/hardware/servo.jpg

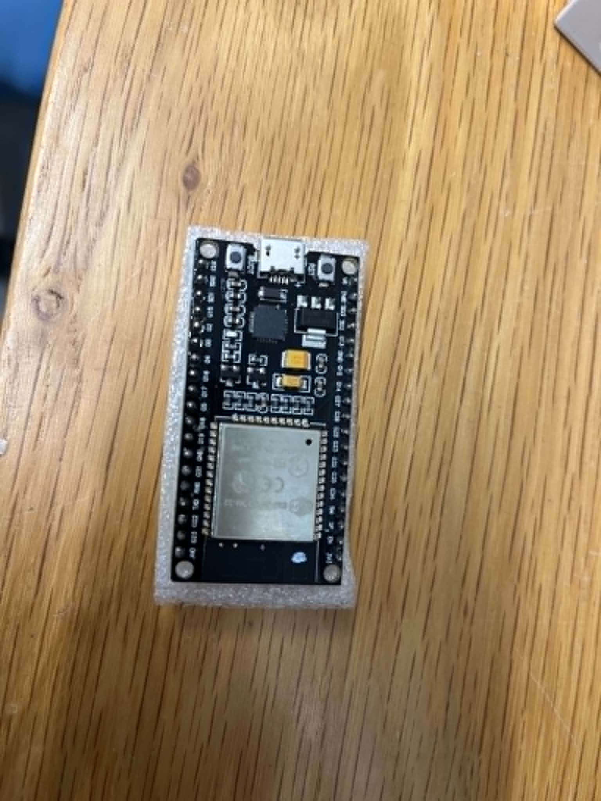
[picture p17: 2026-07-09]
images/hardware/esp32.jpg

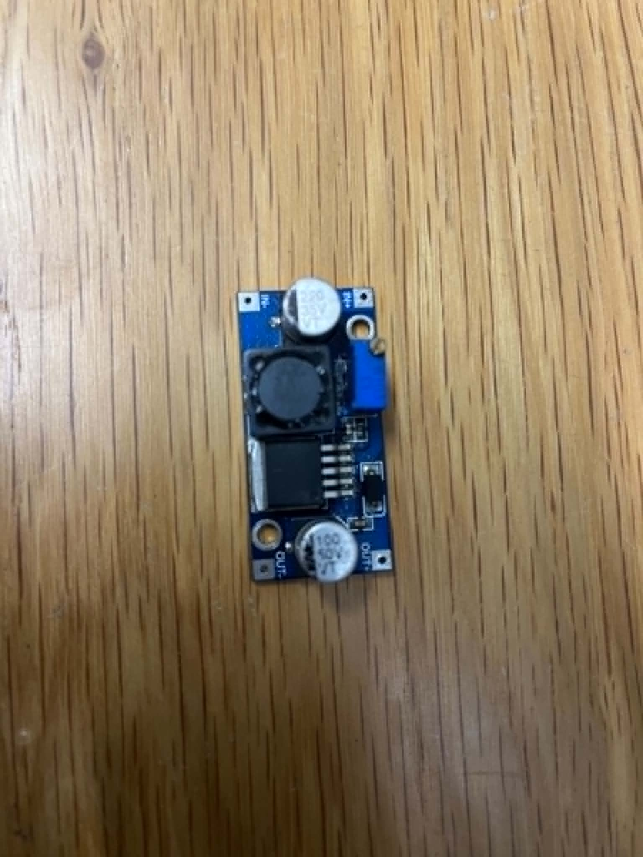
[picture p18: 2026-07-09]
images/hardware/buck_converter.jpg

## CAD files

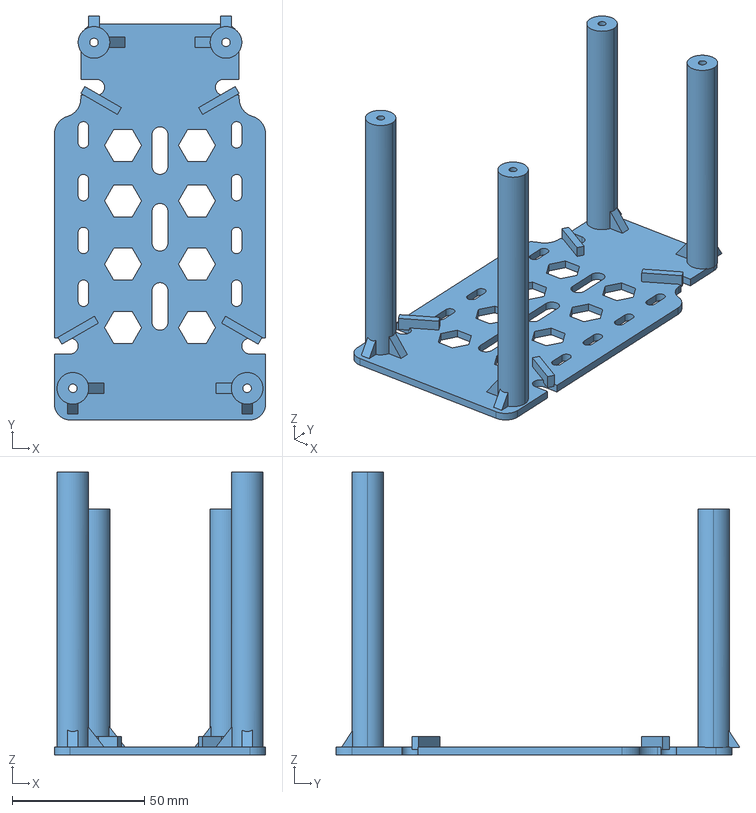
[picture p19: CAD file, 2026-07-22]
cad/custom/main.step
80.0 x 153.0 x 107.0 mm

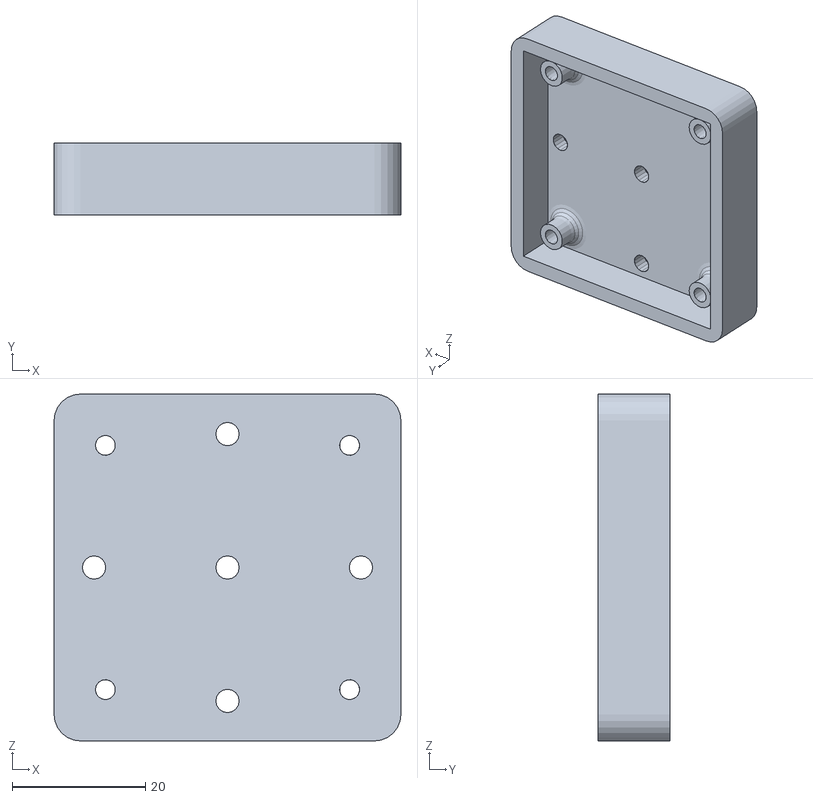
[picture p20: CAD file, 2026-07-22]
cad/l298n_holder/L298N Holder ORP.stl
52.0 x 10.8 x 52.0

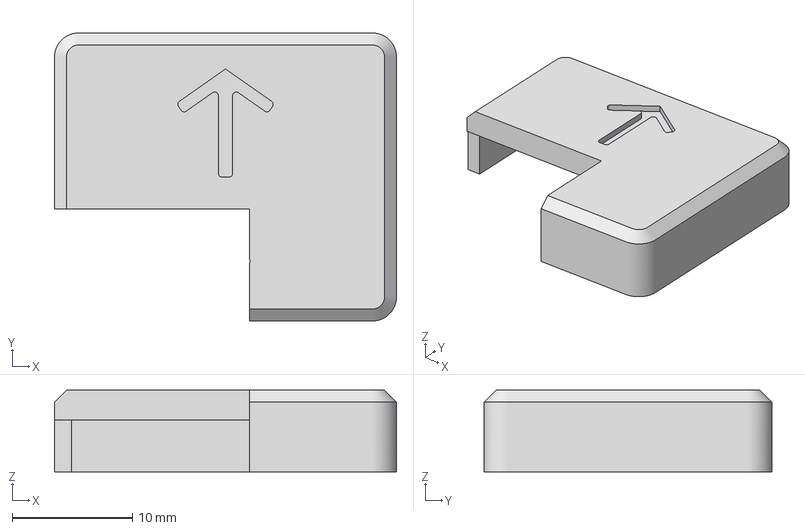
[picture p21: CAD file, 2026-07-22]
cad/mpu6050_enclosure/TOP.3mf
28.5 x 24.0 x 6.80 mm

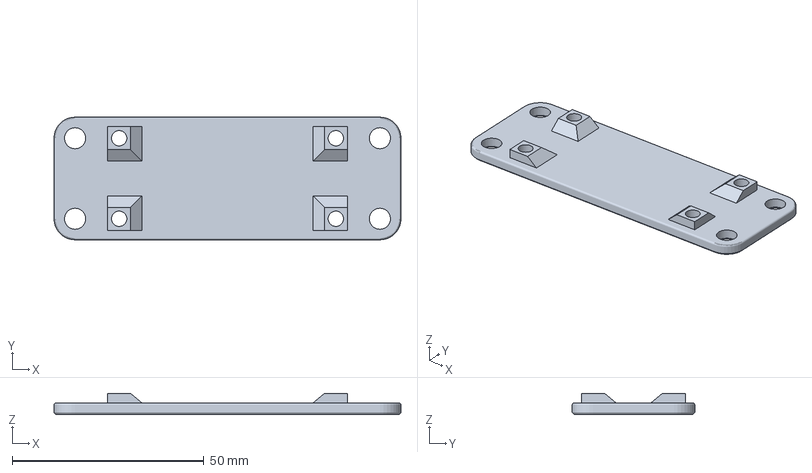
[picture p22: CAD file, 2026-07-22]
cad/xl4015_box/XL4015_Box_P1.3MF
90.5 x 32.0 x 5.50 mm

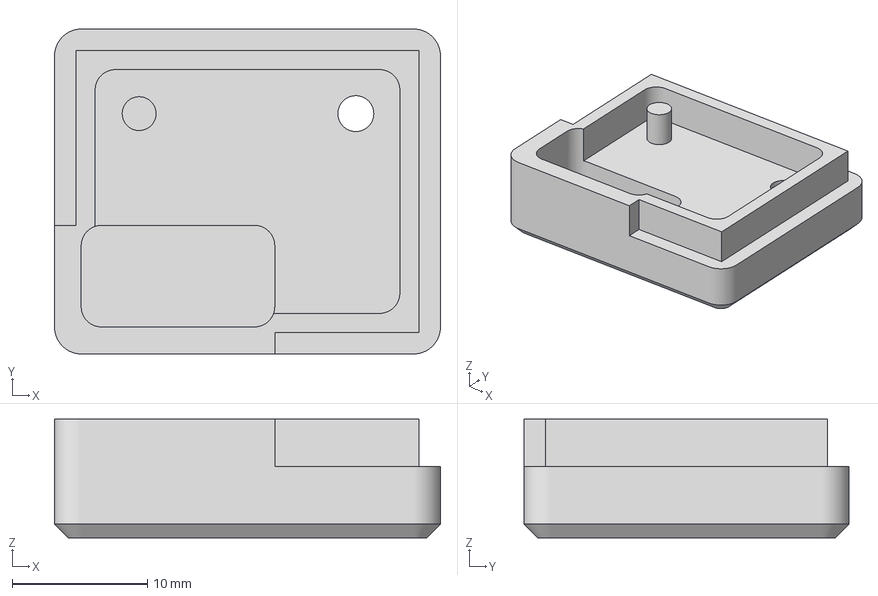
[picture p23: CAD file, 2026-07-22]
cad/mpu6050_enclosure/Bottom.3mf
28.5 x 24.0 x 8.75 mm

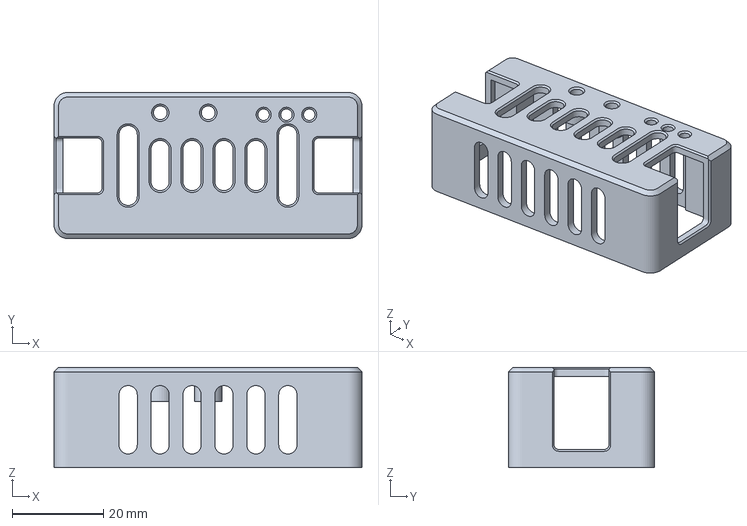
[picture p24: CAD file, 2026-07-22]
cad/xl4015_box/XL4015_Box_P2_v2.3MF
67.5 x 32.0 x 22.0 mm

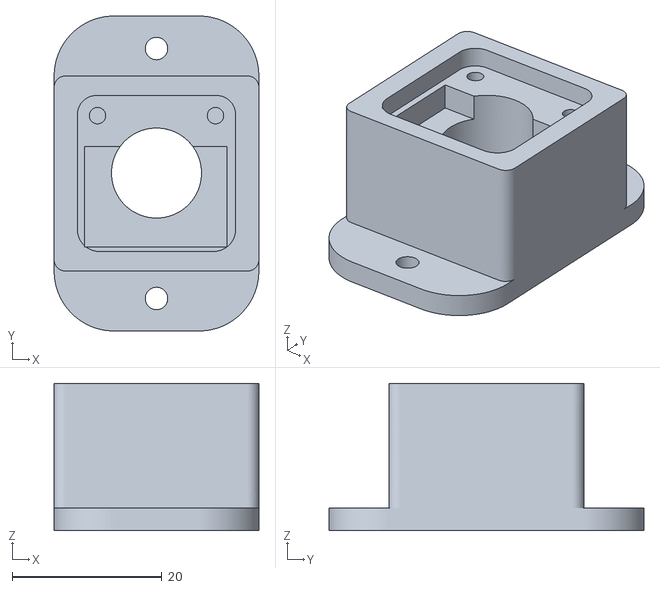
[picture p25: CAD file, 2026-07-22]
cad/tcs34725_cover/TCS34725 cover light detection.stl
27.3 x 42.0 x 19.7

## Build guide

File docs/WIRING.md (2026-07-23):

# Electrical Wiring

The robot is built around an ESP32 DevKit V1 mounted on an ESP32 Expansion Shield, which serves as the main controller for all sensors and actuators. A Raspberry Pi 3 Model B acts as a companion computer for vision processing and communicates with the ESP32 through a UART connection. The Raspberry Pi Camera is connected directly to the Raspberry Pi using the CSI interface.

The power system is supplied by a 2S Li-ion battery. Battery voltage is delivered directly to the L298N motor driver and to an XL4015 DC-DC buck converter. The buck converter is adjusted to provide a stable 5.06 V output, which powers both the ESP32 through its VIN pin and the MG996R steering servo. The main power switch is installed on the battery ground (negative) line, and all components share a common electrical ground.

Two independent I²C buses are used in the system. The first bus (GPIO21 SDA, GPIO22 SCL) connects the two VL53L1X distance sensors together with the MPU6050 IMU. Since both VL53L1X sensors have the same default I²C address, their XSHUT pins are connected to GPIO18 and GPIO19, allowing each sensor to be initialized individually with a unique address. The second I²C bus (GPIO16 SDA, GPIO17 SCL) is dedicated exclusively to the TCS34725 color sensor.

The complete electrical architecture of the robot is illustrated below.

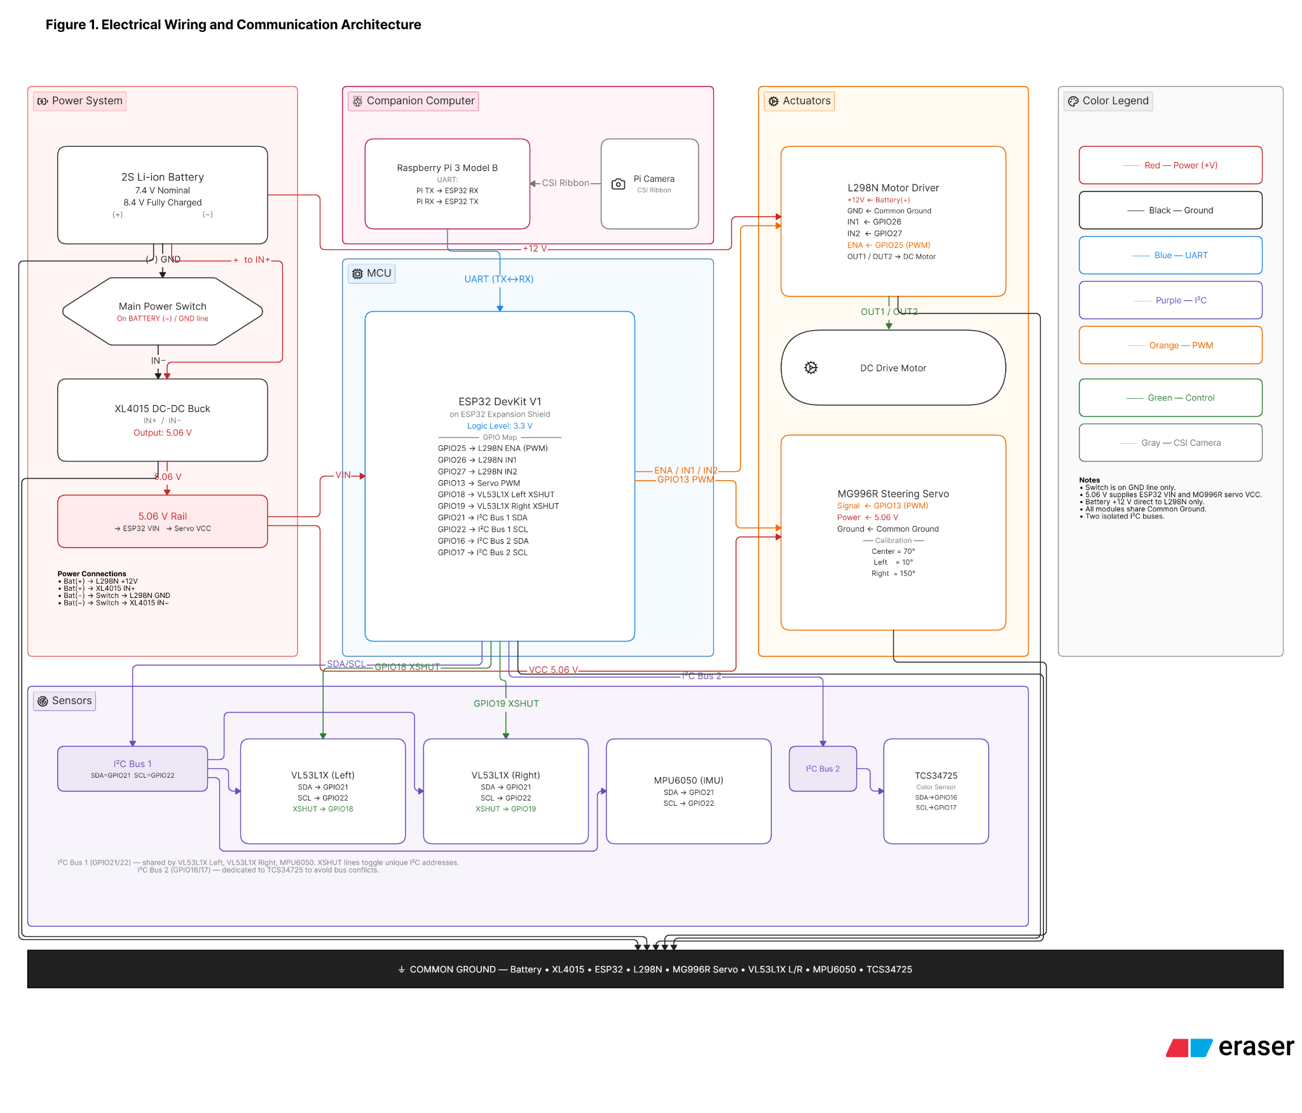
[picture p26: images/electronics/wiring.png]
Electrical Wiring Diagram


**Figure 1.** Electrical wiring and communication architecture of the robot.

---

## Power Distribution

| Source | Destination |
|---|---|
| 2S Li-ion Battery (+) | L298N +12V |
| 2S Li-ion Battery (+) | XL4015 IN+ |
| Battery GND | Main Power Switch |
| Main Power Switch | L298N GND |
| Main Power Switch | XL4015 IN− |
| XL4015 Output (5.06 V) | ESP32 VIN |
| XL4015 Output (5.06 V) | MG996R Servo |

---

## Main Controllers

| Device | Function |
|---|---|
| ESP32 DevKit V1 | Main controller for sensors and actuators |
| Raspberry Pi 3 Model B | Companion computer for vision processing |
| Raspberry Pi Camera | Connected to Raspberry Pi through CSI |

---

## Motor and Steering Control

| Device | Connection |
|---|---|
| L298N ENA | GPIO25 |
| L298N IN1 | GPIO26 |
| L298N IN2 | GPIO27 |
| MG996R Steering Servo | GPIO13 (PWM) |

---

## Sensor Connections

| Sensor | Interface | GPIO |
|---|---|---|
| VL53L1X Left | I²C Bus 1 | SDA GPIO21 / SCL GPIO22 / XSHUT GPIO18 |
| VL53L1X Right | I²C Bus 1 | SDA GPIO21 / SCL GPIO22 / XSHUT GPIO19 |
| MPU6050 IMU | I²C Bus 1 | SDA GPIO21 / SCL GPIO22 |
| TCS34725 Color Sensor | I²C Bus 2 | SDA GPIO16 / SCL GPIO17 |

---

## GPIO Assignment

| GPIO | Function |
|---|---|
| GPIO13 | MG996R Servo PWM |
| GPIO16 | I²C Bus 2 SDA |
| GPIO17 | I²C Bus 2 SCL |
| GPIO18 | VL53L1X Left XSHUT |
| GPIO19 | VL53L1X Right XSHUT |
| GPIO21 | I²C Bus 1 SDA |
| GPIO22 | I²C Bus 1 SCL |
| GPIO25 | L298N ENA (PWM) |
| GPIO26 | L298N IN1 |
| GPIO27 | L298N IN2 |

---

## Communication Interfaces

| Interface | Connected Devices |
|---|---|
| UART | Raspberry Pi ↔ ESP32 |
| I²C Bus 1 | VL53L1X Left, VL53L1X Right, MPU6050 |
| I²C Bus 2 | TCS34725 |
| CSI | Raspberry Pi Camera ↔ Raspberry Pi |

The wiring architecture was designed to provide reliable power distribution, organized communication buses, and clear separation between sensing, control, and actuation subsystems while maintaining a common ground throughout the robot.

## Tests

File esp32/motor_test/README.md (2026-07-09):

# DC Motor Driver Validation Test (L298N)

## Objective

The objective of this test is to verify the correct operation of the L298N motor driver and validate the communication between the ESP32 and the motor driver before integrating the propulsion system into the autonomous vehicle.

This test confirms that the ESP32 can generate the required control signals to drive the DC motor forward, reverse, and stop safely.

---

# Engineering Decision

The L298N motor driver was selected because it provides a simple and reliable solution for controlling the DC propulsion motor during the development of the robot.

The driver supports:

- Forward rotation
- Reverse rotation
- PWM speed control
- Simple GPIO interface with the ESP32

Its straightforward interface makes software debugging and hardware validation easier during the development process.

---

# Hardware Configuration

## Components

- ESP32 DevKit V1
- L298N Motor Driver
- DC Gear Motor

---

## Wiring

| ESP32 GPIO | L298N |
|---|---|
| GPIO25 | IN1 |
| GPIO26 | IN2 |
| GPIO27 | ENA |
| GND | GND |

---

## Motor Connection

| L298N | DC Motor |
|---|---|
| OUT1 | Motor Terminal A |
| OUT2 | Motor Terminal B |

---

## Power

The ESP32 is powered through USB during software testing.

The DC motor requires an external power source and should not be powered directly from the ESP32 USB connection.

---

# Software Description

The test program performs the following sequence:

1. Initialize the GPIO pins.
2. Rotate the motor forward.
3. Stop the motor.
4. Rotate the motor in reverse.
5. Stop the motor.
6. Repeat the cycle continuously.

Serial messages are transmitted to assist with debugging and software verification.

---

# Test Procedure

1. Connect the ESP32 and L298N according to the wiring table.
2. Upload the motor test program.
3. Open the Serial Monitor at **115200 baud**.
4. Verify that the control sequence is executed correctly.
5. If an external power source is connected, verify the motor rotates in both directions.

---

# Expected Output

```text
L298N Motor Test Started

Forward
Stop
Reverse
Stop
```

---

# Test Results

The ESP32 successfully generated all required control signals.

The motor driver correctly received the commands for:

- Forward rotation
- Reverse rotation
- Stop

No communication or GPIO errors were observed during testing.

---

# Engineering Notes

The motor control software was developed as an independent module to simplify debugging and future maintenance.

Separating the propulsion subsystem from the remaining software architecture allows each hardware component to be validated individually before full system integration.

This modular design follows the engineering workflow used throughout the project.

---

# Future Integration

The motor driver module will later be integrated with:

- Steering Controller
- Navigation State Machine
- Obstacle Avoidance
- Vision-Based Navigation
- Safety System

Future improvements include:

- Closed-loop speed control using encoder feedback
- PID speed regulation
- Speed adjustment based on navigation decisions
- Emergency stop handling

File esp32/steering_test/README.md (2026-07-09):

# Steering Test

## Objective

Verify the operation of the steering system using the MG996R servo motor connected to the ESP32.

## Initial Calibration

The first steering angles used were:

| Direction | Angle |
|---|---:|
| Left | 50° |
| Center | 90° |
| Right | 130° |

During testing, the steering was not properly aligned. The wheels did not point straight when the servo was set to 90°, and the left turning angle was insufficient.

## Calibration Process

Several steering angles were tested until the steering linkage was correctly aligned.

The final calibrated values were:

| Direction | Angle |
|---|---:|
| Left | 10° |
| Center | 70° |
| Right | 130° |

## Result

✅ Steering movement verified successfully.

✅ Mechanical alignment improved after calibration.

✅ The calibrated values will be used in future software development.

---

This is the first software test of the WRO Future Engineers robot.

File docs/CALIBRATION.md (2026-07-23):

# Calibration

## Overview

Before each testing session and competition run, the robot is calibrated to ensure consistent and repeatable performance. Calibration minimizes the influence of environmental changes such as lighting conditions, sensor drift, and battery voltage variations.

The calibration procedure is simple and can be completed within a few minutes.

---

## Steering Calibration

The MG996R steering servo is calibrated so that the front wheels are perfectly aligned when the steering command is centered.

The steering limits are configured as follows:

| Steering Position | Value |
|---|---:|
| Left Limit | 10 |
| Center | 70 |
| Right Limit | 150 |

These values were determined experimentally to provide accurate steering while preventing mechanical overtravel.

---

## Distance Sensor Calibration

The two VL53L1X Time-of-Flight sensors are initialized separately using their XSHUT pins.

During startup:

1. The left sensor is enabled and assigned its I²C address.
2. The right sensor is enabled and assigned a different I²C address.
3. Both sensors begin continuous distance measurements.

Before navigation starts, the robot records the initial wall distances. These reference measurements are then used by the wall-following algorithm instead of relying on fixed distance values, allowing the robot to adapt to different starting positions.

---

## IMU Calibration

The MPU6050 is initialized while the robot is stationary.

At startup:

- The initial heading is stored.
- Gyroscope readings are stabilized.
- This heading becomes the reference direction for all subsequent turns.

Using a reference heading helps reduce cumulative turning errors during autonomous navigation.

---

## Color Sensor Calibration

The TCS34725 color sensor is calibrated before operation to ensure reliable marker detection.

Calibration verifies:

- Stable RGB measurements
- Consistent color classification
- Reliable detection under the expected lighting conditions

Threshold values were adjusted experimentally using repeated measurements.

---

## Vision System Calibration

The Raspberry Pi camera is checked before each run to verify:

- Proper camera focus
- Stable image acquisition
- Correct obstacle detection
- Reliable UART communication with the ESP32

The vision system is tested using sample obstacles before autonomous operation.

---

## Power Verification

Before every run, the power system is inspected.

The following items are verified:

- Battery is sufficiently charged.
- XL4015 output remains at approximately 5.06 V.
- Servo and ESP32 receive stable power.
- All ground connections are secure.

Stable power is essential for maintaining consistent sensor readings and reliable motor control.

---

## Pre-Run Checklist

Before starting the robot, the following checks are performed:

- Steering is centered.
- Distance sensors respond correctly.
- IMU initializes successfully.
- Color sensor detects markers correctly.
- Camera detects obstacles.
- UART communication is operational.
- Battery voltage is sufficient.
- All electrical connections are secure.

Only after all checks are completed is the robot ready for autonomous operation.

---

## Final Notes

The calibration process was designed to be quick, repeatable, and reliable. By verifying every major subsystem before operation, the robot maintains stable performance and minimizes the effect of environmental variations during testing and competition.

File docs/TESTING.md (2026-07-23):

# Testing

## Testing Objectives

The objective of the testing process was to verify that all hardware and software components operated reliably under real competition conditions. Each subsystem was tested independently before being integrated into the complete robot. The testing process focused on accuracy, repeatability, stability, and overall navigation performance.

---

## Test Environment

The robot was tested on a practice track designed to replicate the WRO Future Engineers field. Multiple test sessions were performed under different lighting conditions and with repeated laps to evaluate consistency.

The following aspects were evaluated:

- Straight-line driving
- Steering accuracy
- Wall following
- Corner detection
- Obstacle detection
- Color marker recognition
- Vision system reliability
- Full autonomous navigation

---

## Hardware Testing

Each hardware component was verified individually before integration.

| Component | Test Performed | Result |
|---|---|---|
| ESP32 DevKit V1 | GPIO and communication verification | Passed |
| Raspberry Pi 3 Model B | Vision processing and UART communication | Passed |
| Raspberry Pi Camera | Image acquisition and object detection | Passed |
| L298N Motor Driver | Motor direction and PWM control | Passed |
| MG996R Servo | Steering angle calibration | Passed |
| VL53L1X Left | Distance measurement accuracy | Passed |
| VL53L1X Right | Distance measurement accuracy | Passed |
| MPU6050 | Heading and turn angle measurement | Passed |
| TCS34725 | Color marker detection | Passed |
| XL4015 Buck Converter | Stable 5.06 V output | Passed |

---

## Sensor Testing

The distance sensors were tested at multiple wall distances to verify measurement stability and repeatability.

The MPU6050 was tested during repeated left and right turns to validate heading estimation.

The TCS34725 color sensor was tested under different lighting conditions to ensure reliable color classification.

The Raspberry Pi Camera was tested with different obstacle positions and distances to verify consistent object detection.

---

## Motion Testing

Motor speed and steering response were tested independently before autonomous navigation.

The following characteristics were evaluated:

- Smooth acceleration
- Stable steering
- Straight-line tracking
- Turning precision
- Recovery after turns

PWM values and steering calibration were adjusted until repeatable motion was achieved.

---

## Navigation Testing

The complete navigation algorithm was evaluated by performing repeated autonomous laps.

The following behaviors were verified:

- Wall following
- Predictive corner detection
- Obstacle avoidance
- Correct steering direction
- Heading correction using the IMU
- Recovery after obstacle avoidance
- Stable lane positioning

Each software update was validated through repeated runs before being incorporated into the final version.

---

## Vision Testing

The Raspberry Pi vision system was tested independently from the ESP32 controller.

Testing focused on:

- Obstacle detection
- Detection stability
- Communication latency
- Reliable UART data transfer
- Correct synchronization with the ESP32

The communication protocol was verified to ensure accurate command transmission during autonomous driving.

---

## Reliability Testing

Long-duration testing sessions were conducted to evaluate system reliability.

The robot completed multiple consecutive laps while monitoring:

- Sensor stability
- Communication reliability
- Steering consistency
- Power stability
- Navigation repeatability

Special attention was given to maintaining consistent performance throughout the entire run.

---

## Performance Improvements

Testing results were used to refine both hardware and software.

The main improvements included:

- Steering calibration optimization
- More stable wall-following behavior
- Improved corner detection
- Better obstacle avoidance timing
- Reduced sensor noise
- Improved heading correction using the IMU
- Increased navigation consistency

---

## Final Validation

The final version of the robot was validated after completing successful autonomous runs with all subsystems operating simultaneously.

The validation confirmed:

- Reliable hardware operation
- Stable communication between controllers
- Accurate sensor measurements
- Consistent autonomous navigation
- Robust obstacle detection and avoidance
- Repeatable overall performance suitable for competition conditions

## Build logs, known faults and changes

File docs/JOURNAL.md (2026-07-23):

# Engineering Journal

## Project Timeline

This journal documents the engineering development of our WRO Future Engineers 2026 robot from the initial research stage to the final autonomous vehicle.

Instead of documenting only the final robot, this journal records the complete engineering process, including research, design decisions, hardware assembly, software development, testing, failures, improvements, and validation.

---

# Phase 1 — Research & Planning

**Period:** March 2026 – April 2026

## Objective

Before purchasing any hardware, our objective was to understand the competition requirements and design an autonomous robot that would be reliable, modular, and continuously improvable throughout the season.

## Research Questions

| Engineering Question | Why was it important? | Final Decision |
|---|---|---|
| Which controller should control the robot? | Real-time motor and sensor control is essential. | ESP32 |
| Which computing platform should process computer vision? | Camera processing requires higher computational power. | Raspberry Pi 3 Model B |
| Which distance sensor should be used? | Accurate and reliable wall detection. | VL53L1X |
| Which steering mechanism should be used? | Stable autonomous navigation. | Ackermann Steering |
| How should the robot be designed? | Allow future upgrades without rebuilding the robot. | Modular architecture |

## Engineering Goals

Our project was not only about participating in the competition.

We wanted to challenge ourselves by building a complete autonomous robot from scratch and gain practical engineering experience beyond our university courses.

Throughout the project, we focused on learning new technologies, experimenting with different solutions, and continuously improving the robot after every test.

Although learning was our main motivation, we were equally determined to build the best possible robot and compete at the highest level in WRO Future Engineers.

## Engineering Design Meeting 01

<p align="center">
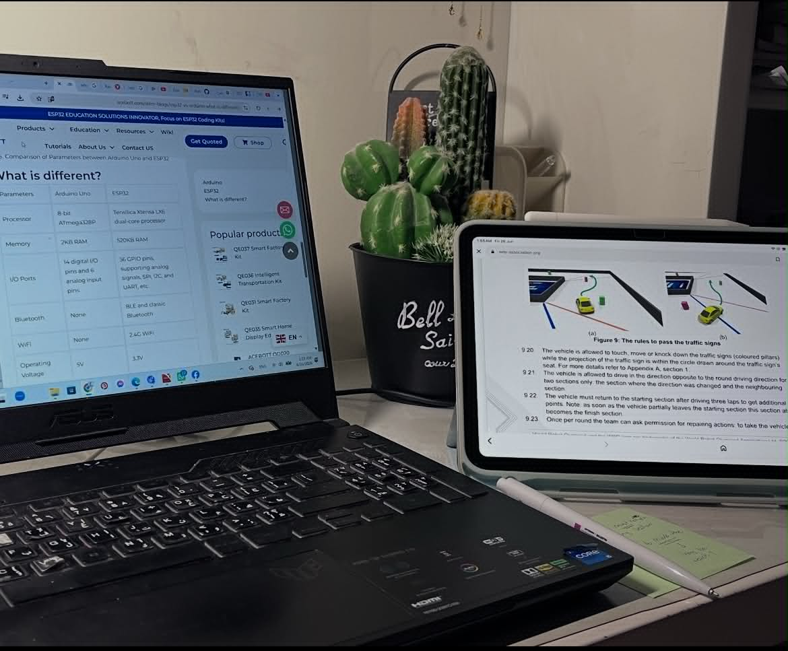
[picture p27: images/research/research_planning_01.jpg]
  
</p>

**Figure 1.** Research and planning session before selecting the robot architecture.

During this stage, we studied the official WRO Future Engineers rules, evaluated different hardware platforms, and compared multiple technical solutions before making any purchasing decisions.

### Objective

Understand the competition requirements and evaluate possible hardware platforms before making engineering decisions.

### Outcome

- Defined the main engineering objectives.
- Identified the robot's functional requirements.
- Selected the initial system architecture for future development.

# Phase 2 — Hardware Assembly

**Period:** June 2026

## Objective

Assemble the mechanical platform and verify that all mechanical components operate correctly before integrating the electronic hardware.

---

## Gearbox Inspection

Before assembling the chassis, we opened the gearbox to inspect the internal gear arrangement and verify that all moving parts were correctly installed.

<p align="center">
  
</p>

**Figure 2.** Internal gearbox inspection before assembly.

During this inspection, we also started analyzing the drivetrain mechanically. The gearbox was opened to understand the internal gear arrangement and prepare for calculating the gear ratio, output torque, and expected wheel speed.

These calculations are important because they help us estimate whether the motor can provide enough torque to move the robot reliably while maintaining an appropriate speed for autonomous navigation.

---

## Mechanical Assembly

The chassis was assembled by installing the gearbox, steering mechanism, suspension components, wheels, and structural parts according to the manufacturer's instructions. During the assembly process, we ensured that all moving parts operated smoothly and that the steering mechanism was correctly aligned.

<p align="center">
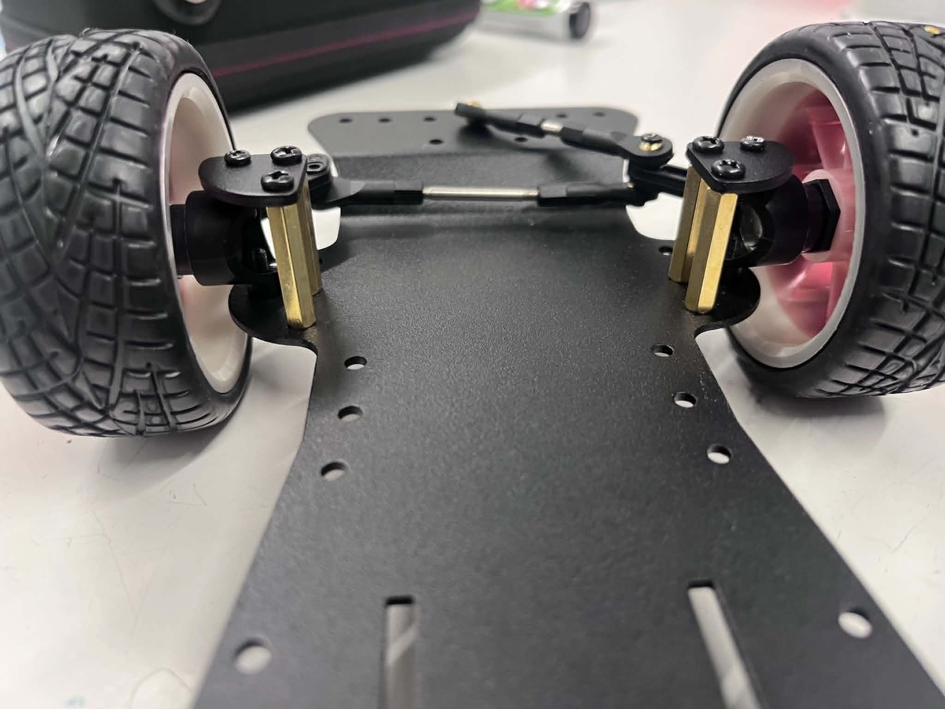
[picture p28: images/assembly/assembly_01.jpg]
  
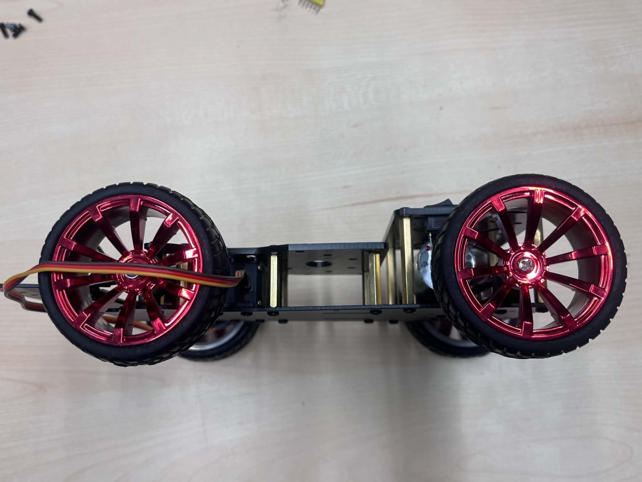
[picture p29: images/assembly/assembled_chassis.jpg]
  
</p>

**Figure 3.** Chassis assembly process and completed mechanical platform.

---

## Mechanical Verification

After completing the chassis assembly, we verified the robot dimensions and measured its weight before starting the electronics integration.

| Width Measurement | Weight Measurement |
|:---:|:---:|
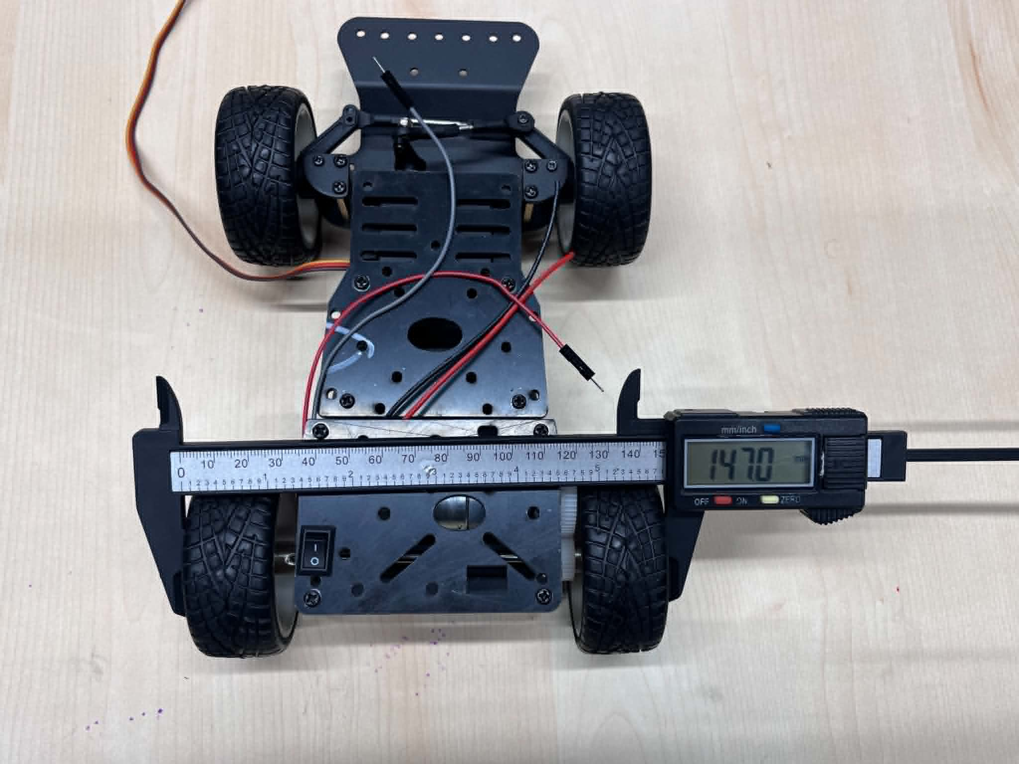
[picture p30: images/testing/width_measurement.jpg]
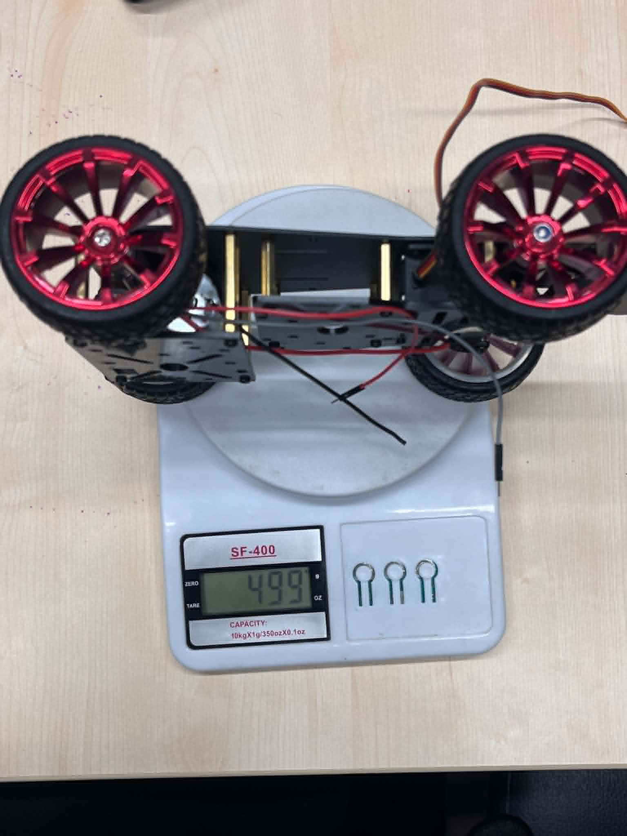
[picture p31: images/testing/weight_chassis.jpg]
|  |  |

**Figure 4.** Initial mechanical verification.

## Phase Summary

The mechanical platform was successfully assembled and verified before integrating the electronic components. At this stage, the robot structure was ready for the next phase, which focused on installing the controllers, sensors, and electrical connections.

# Phase 3 — Electronics Integration

**Period:** June 2026

## Raspberry Pi Evaluation

Before integrating the electronic system, we evaluated the Raspberry Pi 3 Model B as a possible computing platform for future computer vision tasks.

The operating system was installed on a microSD card and the board was powered for the first time. During the initial evaluation, the first Raspberry Pi board showed unstable behavior, which prevented reliable operation. After investigating the issue, the board was replaced and testing continued using another Raspberry Pi 3 Model B.

This experience highlighted the importance of validating hardware before integrating it into the robot and helped us avoid future debugging problems.

## ESP32 Platform Preparation

After evaluating the Raspberry Pi, we prepared the ESP32 development board for sensor integration. An expansion board was used to simplify wiring and improve access to power and communication pins during development.

<p align="center">
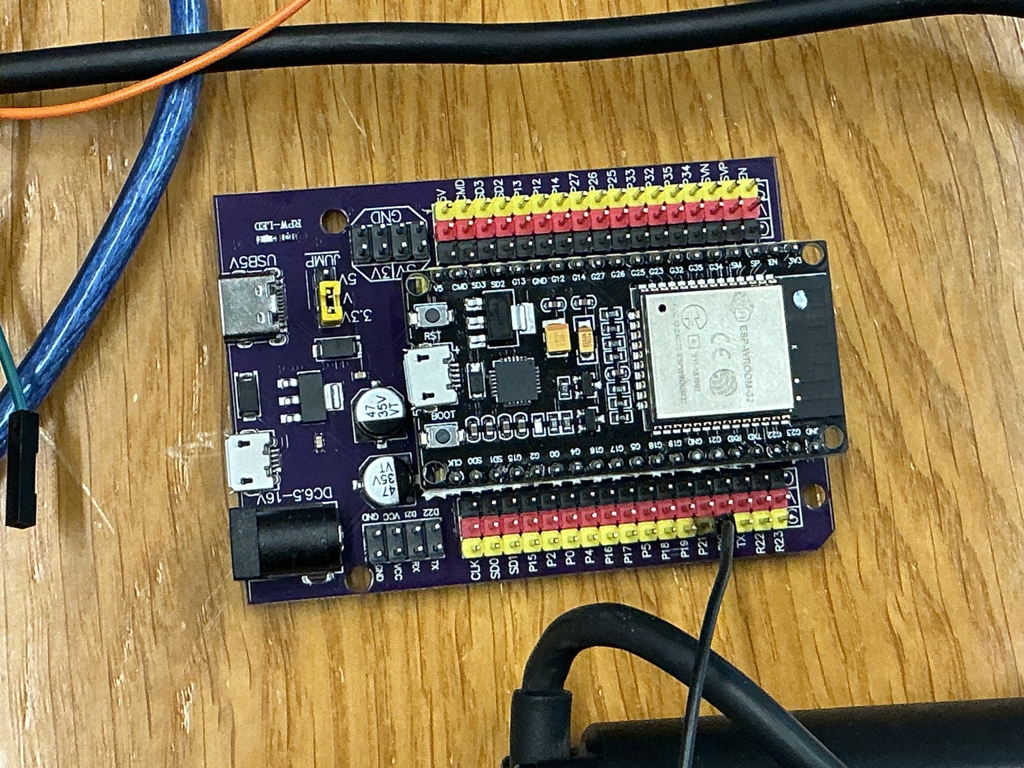
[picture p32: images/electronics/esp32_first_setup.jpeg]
  
</p>

**Figure 7.** Initial ESP32 setup for electronics development.

## Initial Sensor Testing

The development process continued by testing each sensor individually before integrating the complete electronic system.

The MPU6050 IMU and the TCS34725 color sensor were successfully detected and communicated correctly with the ESP32.

The VL53L1X distance sensor was then tested. During this stage, communication issues were encountered while configuring multiple sensors on the same I²C bus. Several software modifications and hardware checks were performed in an attempt to resolve the problem before continuing the integration process.

<p align="center">
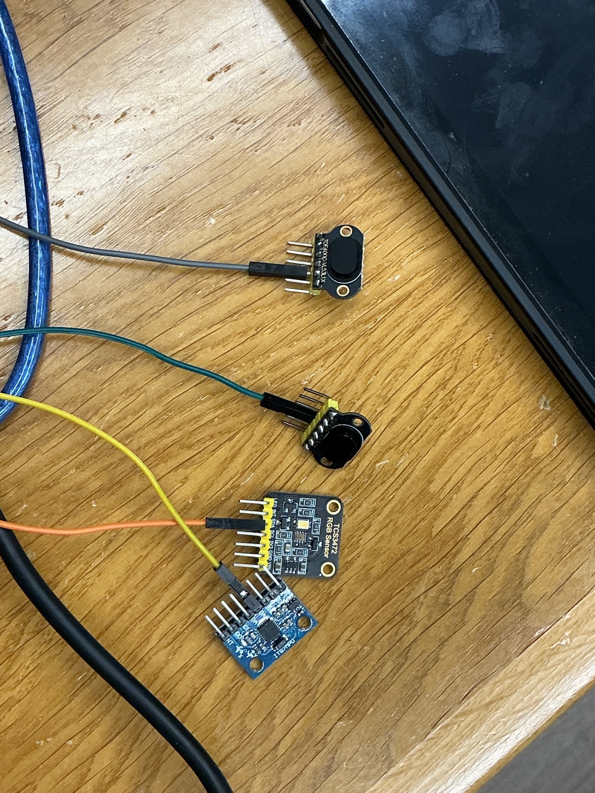
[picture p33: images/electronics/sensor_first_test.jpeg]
  
</p>

**Figure 8.** Initial individual sensor testing using the ESP32.

## Engineering Notes

At the end of this development session, the ESP32 platform had been successfully prepared, the MPU6050 and TCS34725 sensors had been validated, and troubleshooting of the VL53L1X communication issue was still in progress.

Further electronics integration will continue after resolving the I²C communication between the distance sensors.

# Phase 4 — System Integration

**Period:** July 2026

## Objective

Integrate all mechanical, electronic, and software components into a single autonomous robotic platform while ensuring that every subsystem operates reliably under real testing conditions.

Unlike the previous development phases, this stage focused on making every component communicate correctly while maintaining stable performance during continuous operation.

---

## Mechanical and Electronic Integration

After validating the individual hardware components, all electronics were installed inside the robot chassis.

Special attention was given to component placement, cable routing, and power distribution. The objective was not only to make the robot functional, but also to simplify future maintenance and reduce the possibility of loose connections during testing.

The ESP32, Raspberry Pi, motor driver, steering servo, sensors, and voltage regulator were installed while maintaining easy access for troubleshooting and future modifications.

<p align="center">
  
</p>

**Figure 9.** Final wiring and electronics integration.

---

## Power Distribution Verification

Before powering the complete robot, every electrical connection was inspected.

Voltage measurements were performed to verify that each subsystem received the correct supply voltage and that all grounds were properly connected.

Only after confirming the electrical integrity of the system was the robot powered as a complete platform.

This verification reduced the risk of hardware damage during the first full-system startup.

---

## Initial Full-System Validation

The robot was powered with every subsystem connected simultaneously for the first time.

Instead of immediately testing autonomous navigation, every subsystem was verified independently while installed on the completed robot.

The following components were successfully validated:

- ESP32 controller
- Raspberry Pi
- Steering servo
- Drive motor
- MPU6050 IMU
- VL53L1X distance sensors
- TCS34725 color sensor
- Serial communication between controllers

Successful validation confirmed that hardware integration had been completed correctly and that software development could continue safely.

---

## Integration Challenges

Although each component worked correctly when tested individually, integrating them into one complete system introduced additional challenges.

Several debugging sessions were required to verify communication between sensors, ensure stable power delivery, and confirm that multiple subsystems could operate simultaneously without interfering with each other.

These tests demonstrated the importance of validating both individual modules and the complete integrated system.

---

## Phase Summary

At the end of this phase, the robot had evolved from a collection of independent components into a fully integrated robotic platform ready for autonomous software development and field testing.

# Phase 5 — Software Development

**Period:** July 2026

## Objective

Develop reliable and modular software capable of controlling the autonomous robot while allowing continuous improvements throughout the development process.

Rather than writing one large program, the software was divided into independent modules that could be tested, debugged, and improved separately before being integrated into the final system.

---

## Modular Software Architecture

The control software was developed using a modular approach.

Each subsystem was implemented independently to simplify debugging and reduce software complexity.

The first completed software modules included:

- Motor control
- Steering control
- IMU communication
- Distance measurement
- Color detection
- Serial communication between the ESP32 and Raspberry Pi

Testing each module individually allowed problems to be isolated more easily before integrating the complete navigation system.

---

## Sensor Validation

Before implementing autonomous navigation, every sensor was evaluated independently.

Sensor readings were continuously monitored to verify communication stability and measurement consistency.

Special attention was given to the VL53L1X distance sensors and the TCS34725 color sensor, since reliable sensor data is essential for autonomous navigation.

Any unexpected readings were investigated before continuing with software integration.

---

## Color Sensor Calibration

The TCS34725 color sensor required multiple calibration sessions before it could reliably distinguish between the competition markers.

Different lighting conditions produced noticeable changes in the measured RGB values.

To improve reliability, repeated experiments were performed by presenting orange and blue markers to the sensor while observing the measured values through the serial monitor.

Based on these observations, the software thresholds were adjusted several times until the detection became more consistent.

Color calibration remains an ongoing process as additional testing is performed under different environmental conditions.

---

## Autonomous Navigation Development

After validating the individual software modules, work began on autonomous navigation.

Initially, the robot was programmed to perform basic movements such as driving forward, steering accurately, and responding to sensor measurements.

Gradually, additional navigation logic was introduced, allowing the robot to combine information from multiple sensors while making autonomous driving decisions.

The navigation algorithm continued to evolve after every testing session.

---

## Continuous Software Refinement

Software development did not end after the first successful autonomous run.

Instead, every practice session generated new observations that resulted in additional improvements.

Whenever unexpected robot behavior was observed, the software was analyzed and only one parameter was modified before repeating the same experiment.

This systematic approach made it possible to evaluate the effect of each modification independently while avoiding unnecessary changes to already validated modules.

---

## Phase Summary

By the end of this phase, the robot was capable of autonomous operation using integrated sensor data, while its software architecture remained modular, organized, and ready for continuous optimization during field testing.

# Phase 6 — Robot Testing

**Period:** July 2026 – Present

## Objective

Evaluate the robot under realistic competition conditions and continuously improve its mechanical design, electronics, and software through systematic testing and iterative engineering.

Unlike previous phases, the primary objective was no longer to build new features, but to improve the robot's reliability, repeatability, and overall autonomous performance.

---

## Progressive Testing Strategy

Testing followed a structured workflow rather than evaluating the complete robot immediately.

Every new feature was first tested independently before being combined with the rest of the navigation system.

This incremental approach made debugging significantly easier because unexpected behavior could be traced back to a specific subsystem instead of the entire robot.

---

## Bench Testing

Before testing the robot on the practice field, every software modification was verified on the workbench.

Individual components such as the steering servo, drive motor, IMU, distance sensors, and color sensor were tested independently to confirm that they behaved as expected.

Bench testing allowed software problems to be identified quickly before introducing additional variables such as vehicle motion and environmental conditions.

---

## Practice Field Testing

After individual verification, the robot was tested on a practice field designed to simulate the official WRO Future Engineers challenge.

Instead of focusing only on completing the course, every testing session was treated as an engineering experiment.

During each run, observations were recorded regarding the robot's movement, turning behavior, wall-following performance, and overall consistency.

These observations guided the next software modifications.

---

## Color Detection Calibration

Reliable color detection required considerably more testing than initially expected.

The TCS34725 sensor was evaluated under different lighting conditions while repeatedly observing the measured RGB values through the serial monitor.

Orange and blue markers were presented to the sensor multiple times to verify that they were consistently detected before integrating the detection algorithm into the navigation software.

Whenever inconsistent detections were observed, the software thresholds were adjusted and the experiment was repeated.

This iterative calibration process significantly improved the reliability of color recognition.

---

## Turn Timing Evaluation

Determining the correct moment to initiate each turn was another important part of the testing process.

Different turning strategies were evaluated by observing when the robot started steering after detecting a marker.

Small software adjustments were introduced between runs until the turning position became more consistent and repeatable.

Rather than relying on a single successful attempt, every modification was evaluated across multiple consecutive laps.

---

## Wall Following Optimization

Maintaining a stable distance from the wall required continuous refinement.

Although the robot was capable of detecting the wall, achieving smooth and consistent wall following proved to be more challenging.

Several software parameters influencing steering behavior were gradually adjusted after every testing session.

The robot's trajectory was carefully observed before deciding whether a modification represented a genuine improvement.

---

## Long-Term Stability Testing

Some behaviors only became visible after the robot had been operating for several laps.

For example, the robot occasionally completed the first lap successfully but gradually drifted closer to the wall during later laps.

Instead of immediately introducing major software changes, every possible cause was investigated individually.

Possible factors included steering calibration, sensor measurements, navigation parameters, and accumulated heading error.

This systematic investigation helped eliminate unnecessary modifications while improving the robot's long-term stability.

---

## Incremental Software Refinement

Software improvements were introduced gradually throughout development.

After every testing session, only one software parameter was modified before repeating the same experiment.

This approach allowed the effect of every modification to be evaluated independently while avoiding unexpected interactions between multiple simultaneous changes.

As a result, the navigation software became progressively more reliable after each development cycle.

---

## Performance Evaluation

Each testing session was evaluated using multiple engineering criteria instead of simply checking whether the robot completed the course.

The following characteristics were continuously monitored:

- Color detection reliability
- Wall-following consistency
- Steering stability
- Turning accuracy
- Number of successfully completed laps
- Overall repeatability
- Robot behavior after extended operation

Monitoring these characteristics provided objective feedback for future improvements.

---

## Engineering Workflow

Every engineering improvement followed the same structured methodology:

1. Observe the robot's behavior.
2. Identify the possible cause of the problem.
3. Modify one parameter only.
4. Repeat the experiment.
5. Compare the new results with previous observations.
6. Keep the modification only if measurable improvement was achieved.

Following this workflow prevented unnecessary software changes and ensured that every engineering decision was supported by practical testing.

---

## Continuous Improvements

Development is still ongoing.

Every practice session continues to generate new observations that lead to further software tuning, sensor calibration, and mechanical refinements.

The primary objective is no longer adding new features, but improving consistency, repeatability, and overall competition reliability.

---

## Phase Summary

Robot testing transformed the project from a functional autonomous vehicle into a continuously improving engineering platform.

Rather than searching for immediate solutions, repeated observation, experimentation, and evidence-based improvements became the foundation of the entire development process.

# Phase 7 — Design Iterations

**Period:** Throughout the Development Process

## Objective

Improve the robot continuously by analyzing test results and refining both the hardware and software instead of treating the first design as the final solution.

Every engineering modification was introduced only after practical testing demonstrated that an improvement was necessary.

---

## Sensor Position Optimization

The placement of several sensors changed multiple times throughout development.

Although the sensors operated correctly, small changes in their mounting position significantly affected measurement quality, field of view, and overall navigation performance.

Several mounting configurations were evaluated before selecting the final positions that provided the most stable and repeatable measurements.

---

## Mechanical Improvements

The mechanical structure also evolved during development.

Component placement was adjusted to improve weight distribution, simplify maintenance, and reduce unnecessary movement inside the chassis.

Several 3D printed mounts were redesigned after practical testing to improve stability and simplify installation.

Cable routing was also improved to reduce clutter and make future maintenance easier.

---

## Software Evolution

The navigation software changed continuously throughout the project.

Instead of rewriting the complete program after every experiment, individual modules were refined independently.

Wall-following algorithms, color detection thresholds, steering behavior, and navigation parameters were gradually improved after every testing session.

This modular development strategy reduced debugging time while allowing previously validated software components to remain unchanged.

---

## Continuous Design Improvements

Every testing session produced new engineering observations.

Rather than considering unexpected behavior as a failure, each observation became an opportunity to improve the robot.

Small engineering refinements accumulated throughout the season, resulting in a robot that became progressively more reliable, stable, and predictable.

---

## Phase Summary

The robot's final design was not created in a single step.

Instead, it was the result of continuous engineering iterations driven by testing, observation, analysis, and evidence-based improvements.

# Phase 8 — Engineering Challenges

## Objective

Identify technical challenges encountered during development and describe the engineering process used to overcome them.

Rather than avoiding problems, each challenge became an opportunity to better understand the robot and improve its overall performance.

---

## Challenge 1 — I²C Communication

One of the earliest technical challenges involved establishing reliable communication with multiple VL53L1X distance sensors on the same I²C bus.

Several software configurations and hardware adjustments were evaluated before achieving stable initialization and communication.

This experience reinforced the importance of validating every subsystem independently before integrating the complete robot.

---

## Challenge 2 — Color Detection Reliability

Reliable color detection proved to be more complex than initially expected.

Lighting conditions affected the measured RGB values, making fixed threshold values insufficient during early testing.

Repeated calibration sessions were performed while observing live sensor readings, allowing the detection algorithm to be refined gradually until more consistent performance was achieved.

---

## Challenge 3 — Navigation Consistency

Although the robot could complete individual laps successfully, maintaining consistent behavior over repeated laps required considerably more development.

Small deviations gradually accumulated during extended operation, occasionally causing the robot to approach the wall more closely than intended.

Instead of introducing large software changes, every parameter was evaluated independently until repeatability improved.

---

## Challenge 4 — Software Optimization

As additional navigation features were introduced, maintaining organized and readable software became increasingly important.

The software architecture was continuously reorganized into independent modules, simplifying debugging and reducing the risk of introducing new errors while implementing additional features.

---

## Phase Summary

Each engineering challenge improved both the robot and our engineering methodology.

The experience gained while solving these problems became as valuable as the final technical solutions themselves.

# Lessons Learned

Developing an autonomous robot required much more than assembling hardware and writing software.

Throughout the project we learned to:

- Evaluate engineering trade-offs before making technical decisions.
- Design modular hardware that simplifies future upgrades.
- Validate individual components before complete system integration.
- Debug hardware and software systematically.
- Base engineering decisions on experimental observations instead of assumptions.
- Improve system reliability through continuous iteration.
- Document every stage of development for future reference.

Perhaps the most valuable lesson was understanding that successful engineering is an iterative process built on testing, observation, and continuous refinement rather than immediate perfection.

# Future Improvements

Although the robot is fully operational, development continues beyond the current competition season.

Future work may include:

- Further optimization of computer vision algorithms.
- Additional improvements to navigation consistency.
- More advanced sensor fusion techniques.
- Mechanical redesign of selected 3D printed components.
- Additional software optimization for faster decision making.
- Continued testing under different environmental conditions.
- Further refinement of autonomous driving strategies.

Continuous improvement remains one of the primary engineering principles of this project.

# Final Reflection

The development of our WRO Future Engineers robot has been a multidisciplinary engineering journey involving mechanical design, electronics, embedded programming, computer vision, testing, and autonomous navigation.

Rather than focusing only on producing a competition robot, this project challenged us to think systematically, evaluate engineering trade-offs, validate ideas experimentally, and improve our work through continuous iteration.

Every successful test, unexpected behavior, and engineering challenge contributed to a better understanding of autonomous robotic systems.

The robot presented in this repository is therefore much more than the final result—it represents months of research, experimentation, teamwork, engineering decisions, and continuous improvement.

Most importantly, this project strengthened our ability to approach complex engineering problems with patience, structured thinking, and evidence-based decision making, skills that will continue to benefit us in future engineering projects.

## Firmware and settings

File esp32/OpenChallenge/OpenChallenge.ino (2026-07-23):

/*
  WRO Future Engineers 2026
  OPEN CHALLENGE
  FIXED CORNER DETECTION + SAFE POST-TURN ALIGNMENT
*/

#include <Wire.h>
#include <math.h>
#include <Adafruit_VL53L1X.h>
#include <Adafruit_TCS34725.h>
#include <Adafruit_MPU6050.h>
#include <Adafruit_Sensor.h>
#include <ESP32Servo.h>

namespace BuildConfig {
  constexpr const char* VERSION = "WRO-FE-2026-POST-TURN-FIX";

  constexpr bool ENABLE_DYNAMIC_BRAKE = false;
  constexpr uint32_t DYNAMIC_BRAKE_DURATION_MS = 55;
}

namespace Pins {
  constexpr uint8_t MAIN_SDA = 21;
  constexpr uint8_t MAIN_SCL = 22;

  constexpr uint8_t LEFT_XSHUT  = 18;
  constexpr uint8_t RIGHT_XSHUT = 19;
  constexpr int8_t TOF_IRQ = -1;

  constexpr uint8_t COLOR_SDA = 16;
  constexpr uint8_t COLOR_SCL = 17;

  constexpr uint8_t MOTOR_ENA = 25;
  constexpr uint8_t MOTOR_IN1 = 26;
  constexpr uint8_t MOTOR_IN2 = 27;

  constexpr uint8_t SERVO = 13;
}

namespace SteeringConfig {
  constexpr int CENTER = 70;

  // الحدود الميكانيكية القصوى للسيرفو
  constexpr int HARD_LEFT  = 25;
  constexpr int HARD_RIGHT = 115;

  /*
    حدود التتبع العادي.
    لا نسمح للسيرفو أثناء السير العادي أن يصل لليمين القوي
    حتى لا يعلق أو يصدر صوت زن.
  */
  constexpr int FOLLOW_LEFT_LIMIT  = 52;
  constexpr int FOLLOW_RIGHT_LIMIT = 86;

  // حدود التمركز بين الحائطين بعد اللفة
  constexpr int ALIGN_LEFT_LIMIT  = 54;
  constexpr int ALIGN_RIGHT_LIMIT = 84;

  // زوايا اللفة نفسها
  constexpr int TURN_LEFT  = 30;
  constexpr int TURN_RIGHT = 112;

  constexpr uint16_t SERVO_MIN_PULSE_US = 500;
  constexpr uint16_t SERVO_MAX_PULSE_US = 2500;

  // سرعة انتقال السيرفو بين الزوايا
  constexpr float MAX_STEERING_RATE_DEG_PER_SEC = 1500.0f;
}

namespace MotorConfig {
  constexpr uint32_t PWM_FREQUENCY_HZ = 15000;
  constexpr uint8_t PWM_RESOLUTION_BITS = 8;

  constexpr int PWM_MIN = 0;
  constexpr int PWM_MAX = 255;

  constexpr int MIN_EFFECTIVE_PWM = 175;

  constexpr int START_SPEED = 178;
  constexpr int CRUISE_SPEED = 176;

  constexpr int TURN_FAST_SPEED = 185;
  constexpr int TURN_SLOW_SPEED = 176;

  constexpr int WALL_RECOVERY_SPEED = 176;

  constexpr int ACCEL_STEP_PWM = 8;
  constexpr int DECEL_STEP_PWM = 10;

  constexpr uint32_t RAMP_INTERVAL_MS = 8;
}

namespace DistanceConfig {
  constexpr int DEFAULT_WALL_DISTANCE_MM = 250;

  constexpr int MIN_VALID_MM = 30;
  constexpr int MAX_VALID_MM = 2500;

  constexpr uint32_t SENSOR_STALE_TIMEOUT_MS = 400;

  constexpr uint8_t MEDIAN_WINDOW = 3;

  // فلتر التتبع العادي
  constexpr float FILTER_ALPHA = 0.38f;

  // فلتر سريع لاكتشاف الفراغ
  constexpr float OPENING_FILTER_ALPHA = 0.88f;

  /*
    تتبع الحائط.
    خففنا KD حتى لا تضرب قراءة الدخلة السيرفو بقوة.
  */
  constexpr float WALL_KP = 0.065f;
  constexpr float WALL_KD = 0.008f;

  constexpr int WALL_ERROR_DEADBAND_MM = 10;

  /*
    تمركز الروبوت بين الحائطين بعد اللفة.
  */
  constexpr float CORRIDOR_CENTER_KP = 0.060f;
  constexpr int CORRIDOR_CENTER_DEADBAND_MM = 15;
  constexpr float MAX_CORRIDOR_CORRECTION_DEG = 14.0f;
}

namespace CornerConfig {
  // مقدار ارتفاع قراءة الحائط حتى نعتبره فراغًا
  constexpr int MIN_RELATIVE_OPENING_RISE_MM = 70;

  // منع اكتشاف نفس الفراغ مرتين
  constexpr uint32_t CORNER_LOCKOUT_MS = 800;

  /*
    وقت قصير بعد اللفة يبقى فيه السيرفو سنتر
    حتى يخرج الروبوت من زاوية الدخلة.
  */
  constexpr uint32_t BLIND_EXIT_DURATION_MS = 170;

  // أقصى وقت للبحث عن الحائط الجديد
  constexpr uint32_t WALL_RECOVERY_TIMEOUT_MS = 2000;

  /*
    مدة التمركز بعد رؤية الحائط الجديد.
    كانت 150ms وهي قصيرة جدًا.
  */
  constexpr uint32_t ALIGN_DURATION_MS = 500;

  /*
    أي قراءة أبعد من هذه القيمة لا نعتبرها حائطًا جديدًا.
    غالبًا تكون فراغًا أو قراءة زاوية غير مستقرة.
  */
  constexpr int NEW_WALL_MAX_DISTANCE_MM = 650;

  // عدد القراءات الجديدة المطلوبة قبل دخول الاستعدال
  constexpr uint8_t NEW_WALL_CONFIRMATIONS = 3;
}

namespace TurnConfig {
  constexpr float TARGET_YAW_DEG = 88.0f;
  constexpr float SLOWDOWN_START_DEG = 75.0f;

  constexpr float BRAKE_PREDICTION_TIME_SEC = 0.035f;

  constexpr float MAX_EXIT_RATE_DPS = 25.0f;
  constexpr float MIN_ACCEPTABLE_YAW_DEG = 85.0f;

  constexpr uint8_t SETTLE_CONFIRMATIONS = 2;

  constexpr uint32_t TURN_HARD_LIMIT_MS = 3500;
}

TwoWire colorWire(1);

Adafruit_VL53L1X leftSensor(
  Pins::LEFT_XSHUT,
  Pins::TOF_IRQ
);

Adafruit_VL53L1X rightSensor(
  Pins::RIGHT_XSHUT,
  Pins::TOF_IRQ
);

Adafruit_MPU6050 mpu;

Adafruit_TCS34725 colorSensor(
  TCS34725_INTEGRATIONTIME_24MS,
  TCS34725_GAIN_4X
);

Servo steeringServo;

enum class RobotState : uint8_t {
  Booting,
  FollowingWall,
  TurningCorner,
  FindingNewWall,
  AligningToWall,
  EmergencyStop
};

struct DistanceReading {
  int rawMm = -1;

  float filteredMm = NAN;
  float previousFilteredMm = NAN;
  float rateMmPerSec = 0.0f;

  float openingFilteredMm = NAN;

  int history[DistanceConfig::MEDIAN_WINDOW] = {0};

  uint8_t historyCount = 0;
  uint8_t historyIndex = 0;

  uint32_t timestampMs = 0;

  bool valid = false;
  bool fresh = false;
};

struct ImuRuntime {
  bool ready = false;
  bool calibrated = false;

  float gyroBiasRadPerSec = 0.0f;

  float yawDeg = 0.0f;
  float angularVelocityDps = 0.0f;

  uint32_t lastUpdateMicros = 0;
  uint32_t lastGoodUpdateMs = 0;
};

struct SteeringRuntime {
  float targetAngle = SteeringConfig::CENTER;
  float appliedAngle = SteeringConfig::CENTER;

  uint32_t lastUpdateMs = 0;
};

struct CornerRuntime {
  float stableWallBaselineMm = NAN;

  uint32_t turnStartMs = 0;
  uint32_t lastCornerMs = 0;

  bool turnLeft = false;
  bool turnBrakingActive = false;

  uint8_t turnSettleReadings = 0;
  uint8_t newWallReadings = 0;

  /*
    نخزن توقيت آخر قراءة احتسبناها،
    حتى لا نعد نفس قراءة الحساس أكثر من مرة.
  */
  uint32_t lastNewWallSampleMs = 0;
};

struct MotorRuntime {
  int targetPwm = 0;
  int appliedPwm = 0;

  uint32_t lastRampUpdateMs = 0;
  uint32_t brakeUntilMs = 0;

  bool braking = false;
};

struct RobotRuntime {
  RobotState state = RobotState::Booting;

  DistanceReading leftDistance;
  DistanceReading rightDistance;

  ImuRuntime imu;
  SteeringRuntime steering;
  CornerRuntime corner;
  MotorRuntime motor;

  bool innerWallIsLeft = true;

  uint32_t stateEnteredMs = 0;
};

RobotRuntime robot;

bool isDistanceValid(int distanceMm) {
  return distanceMm >= DistanceConfig::MIN_VALID_MM &&
         distanceMm <= DistanceConfig::MAX_VALID_MM;
}

bool isDistanceFresh(const DistanceReading& reading) {
  return reading.valid &&
         (millis() - reading.timestampMs <=
          DistanceConfig::SENSOR_STALE_TIMEOUT_MS);
}

const DistanceReading& followedWallReadingConst() {
  return robot.innerWallIsLeft
    ? robot.leftDistance
    : robot.rightDistance;
}

int clampSteeringAngle(int angle) {
  return constrain(
    angle,
    SteeringConfig::HARD_LEFT,
    SteeringConfig::HARD_RIGHT
  );
}

void setSteeringImmediate(int angle) {
  const int safeAngle = clampSteeringAngle(angle);

  robot.steering.targetAngle = safeAngle;
  robot.steering.appliedAngle = safeAngle;
  robot.steering.lastUpdateMs = millis();

  steeringServo.write(safeAngle);
}

void setSteeringTarget(int angle) {
  robot.steering.targetAngle =
    clampSteeringAngle(angle);
}

void steerCenter() {
  setSteeringTarget(SteeringConfig::CENTER);
}

void updateSteeringActuator() {
  const uint32_t nowMs = millis();

  if (robot.steering.lastUpdateMs == 0) {
    robot.steering.lastUpdateMs = nowMs;
    return;
  }

  float dtSeconds = constrain(
    (nowMs - robot.steering.lastUpdateMs) / 1000.0f,
    0.0f,
    0.05f
  );

  robot.steering.lastUpdateMs = nowMs;

  const float maxStep =
    SteeringConfig::MAX_STEERING_RATE_DEG_PER_SEC *
    dtSeconds;

  const float error =
    robot.steering.targetAngle -
    robot.steering.appliedAngle;

  if (fabsf(error) <= maxStep) {
    robot.steering.appliedAngle =
      robot.steering.targetAngle;
  }
  else if (error > 0.0f) {
    robot.steering.appliedAngle += maxStep;
  }
  else {
    robot.steering.appliedAngle -= maxStep;
  }

  steeringServo.write(
    static_cast<int>(
      roundf(robot.steering.appliedAngle)
    )
  );
}

void enterState(RobotState newState) {
  robot.state = newState;
  robot.stateEnteredMs = millis();
}

uint32_t timeInCurrentStateMs() {
  return millis() - robot.stateEnteredMs;
}

int clampMotorPwm(int pwm) {
  return constrain(
    pwm,
    MotorConfig::PWM_MIN,
    MotorConfig::PWM_MAX
  );
}

void applyMotorPwmImmediate(int pwm) {
  pwm = clampMotorPwm(pwm);

  if (pwm <= 0) {
    ledcWrite(Pins::MOTOR_ENA, 0);

    digitalWrite(Pins::MOTOR_IN1, LOW);
    digitalWrite(Pins::MOTOR_IN2, LOW);

    robot.motor.appliedPwm = 0;
    return;
  }

  digitalWrite(Pins::MOTOR_IN1, HIGH);
  digitalWrite(Pins::MOTOR_IN2, LOW);

  ledcWrite(Pins::MOTOR_ENA, pwm);

  robot.motor.appliedPwm = pwm;
}

void setMotorTarget(int pwm) {
  pwm = clampMotorPwm(pwm);

  robot.motor.targetPwm =
    (pwm <= 0)
      ? 0
      : max(pwm, MotorConfig::MIN_EFFECTIVE_PWM);
}

void motorForward(int pwm) {
  setMotorTarget(pwm);
}

void motorCoastStop() {
  robot.motor.targetPwm = 0;
  robot.motor.braking = false;

  applyMotorPwmImmediate(0);
}

void motorBrakeStop() {
  robot.motor.targetPwm = 0;

  if (!BuildConfig::ENABLE_DYNAMIC_BRAKE) {
    motorCoastStop();
    return;
  }

  robot.motor.braking = true;

  robot.motor.brakeUntilMs =
    millis() +
    BuildConfig::DYNAMIC_BRAKE_DURATION_MS;

  digitalWrite(Pins::MOTOR_IN1, HIGH);
  digitalWrite(Pins::MOTOR_IN2, HIGH);

  ledcWrite(Pins::MOTOR_ENA, 255);

  robot.motor.appliedPwm = 0;
}

void updateMotorActuator() {
  const uint32_t nowMs = millis();

  if (robot.motor.braking) {
    if (
      static_cast<int32_t>(
        nowMs - robot.motor.brakeUntilMs
      ) < 0
    ) {
      return;
    }

    robot.motor.braking = false;
    applyMotorPwmImmediate(0);
  }

  if (robot.motor.lastRampUpdateMs == 0) {
    robot.motor.lastRampUpdateMs = nowMs;
    return;
  }

  if (
    nowMs - robot.motor.lastRampUpdateMs <
    MotorConfig::RAMP_INTERVAL_MS
  ) {
    return;
  }

  robot.motor.lastRampUpdateMs = nowMs;

  int current = robot.motor.appliedPwm;
  const int target = robot.motor.targetPwm;

  if (current == target) {
    return;
  }

  if (current == 0 && target > 0) {
    current = min(
      target,
      MotorConfig::MIN_EFFECTIVE_PWM
    );

    applyMotorPwmImmediate(current);
    return;
  }

  if (current < target) {
    current = min(
      target,
      current + MotorConfig::ACCEL_STEP_PWM
    );
  }
  else {
    current = max(
      target,
      current - MotorConfig::DECEL_STEP_PWM
    );
  }

  applyMotorPwmImmediate(current);
}

int calculateMedian(
  const int* values,
  uint8_t count
) {
  if (count == 0) {
    return -1;
  }

  int sorted[DistanceConfig::MEDIAN_WINDOW];

  for (uint8_t i = 0; i < count; i++) {
    sorted[i] = values[i];
  }

  for (uint8_t i = 1; i < count; i++) {
    int key = sorted[i];
    int8_t j = i - 1;

    while (j >= 0 && sorted[j] > key) {
      sorted[j + 1] = sorted[j];
      j--;
    }

    sorted[j + 1] = key;
  }

  return sorted[count / 2];
}

void pushDistanceSample(
  DistanceReading& reading,
  int distanceMm,
  uint32_t nowMs
) {
  reading.rawMm = distanceMm;

  if (!isDistanceValid(distanceMm)) {
    return;
  }

  reading.history[reading.historyIndex] =
    distanceMm;

  reading.historyIndex =
    (reading.historyIndex + 1) %
    DistanceConfig::MEDIAN_WINDOW;

  if (
    reading.historyCount <
    DistanceConfig::MEDIAN_WINDOW
  ) {
    reading.historyCount++;
  }

  int medianMm = calculateMedian(
    reading.history,
    reading.historyCount
  );

  if (medianMm < 0) {
    return;
  }

  float oldFiltered = reading.filteredMm;
  uint32_t oldTimestamp = reading.timestampMs;

  reading.previousFilteredMm = oldFiltered;

  if (isnan(oldFiltered)) {
    reading.filteredMm = medianMm;
    reading.rateMmPerSec = 0.0f;
  }
  else {
    reading.filteredMm =
      DistanceConfig::FILTER_ALPHA * medianMm +
      (1.0f - DistanceConfig::FILTER_ALPHA) *
      oldFiltered;

    float dt =
      (nowMs - oldTimestamp) / 1000.0f;

    reading.rateMmPerSec =
      (dt > 0.001f)
        ? (reading.filteredMm - oldFiltered) / dt
        : 0.0f;
  }

  if (isnan(reading.openingFilteredMm)) {
    reading.openingFilteredMm = distanceMm;
  }
  else {
    reading.openingFilteredMm =
      DistanceConfig::OPENING_FILTER_ALPHA *
      distanceMm +
      (1.0f -
       DistanceConfig::OPENING_FILTER_ALPHA) *
      reading.openingFilteredMm;
  }

  reading.timestampMs = nowMs;
  reading.valid = true;
  reading.fresh = true;
}

void updateTofSensors() {
  if (leftSensor.dataReady()) {
    pushDistanceSample(
      robot.leftDistance,
      leftSensor.distance(),
      millis()
    );

    leftSensor.clearInterrupt();
  }

  if (rightSensor.dataReady()) {
    pushDistanceSample(
      robot.rightDistance,
      rightSensor.distance(),
      millis()
    );

    rightSensor.clearInterrupt();
  }

  robot.leftDistance.fresh =
    isDistanceFresh(robot.leftDistance);

  robot.rightDistance.fresh =
    isDistanceFresh(robot.rightDistance);
}

bool readGyroZRadPerSec(float& gyroZ) {
  sensors_event_t a;
  sensors_event_t g;
  sensors_event_t temp;

  mpu.getEvent(&a, &g, &temp);

  gyroZ = g.gyro.z;

  return isfinite(gyroZ);
}

bool calibrateGyroZ() {
  float gyroZ = 0.0f;

  for (uint16_t i = 0; i < 50; i++) {
    readGyroZRadPerSec(gyroZ);
    delay(3);
  }

  double mean = 0.0;

  for (uint16_t i = 1; i <= 300; i++) {
    readGyroZRadPerSec(gyroZ);

    mean += (gyroZ - mean) / i;

    delay(3);
  }

  robot.imu.gyroBiasRadPerSec = mean;
  robot.imu.calibrated = true;

  return true;
}

bool initializeMpu() {
  if (!mpu.begin(0x68, &Wire)) {
    return false;
  }

  mpu.setAccelerometerRange(
    MPU6050_RANGE_4_G
  );

  mpu.setGyroRange(
    MPU6050_RANGE_500_DEG
  );

  mpu.setFilterBandwidth(
    MPU6050_BAND_21_HZ
  );

  delay(100);

  calibrateGyroZ();

  robot.imu.yawDeg = 0.0f;
  robot.imu.lastUpdateMicros = micros();
  robot.imu.lastGoodUpdateMs = millis();
  robot.imu.ready = true;

  return true;
}

void resetYaw() {
  robot.imu.yawDeg = 0.0f;
  robot.imu.angularVelocityDps = 0.0f;
  robot.imu.lastUpdateMicros = micros();
}

void updateImu() {
  if (
    !robot.imu.ready ||
    !robot.imu.calibrated
  ) {
    return;
  }

  uint32_t nowMicros = micros();

  float dt =
    (nowMicros - robot.imu.lastUpdateMicros) /
    1000000.0f;

  robot.imu.lastUpdateMicros = nowMicros;

  if (dt < 0.0005f || dt > 0.080f) {
    return;
  }

  float rawZ = 0.0f;

  if (!readGyroZRadPerSec(rawZ)) {
    return;
  }

  float rateDps =
    (rawZ - robot.imu.gyroBiasRadPerSec) *
    57.2957795f;

  if (fabsf(rateDps) < 0.65f) {
    rateDps = 0.0f;
  }

  robot.imu.angularVelocityDps = rateDps;
  robot.imu.yawDeg += rateDps * dt;
  robot.imu.lastGoodUpdateMs = millis();
}

bool initializeSingleTof(
  Adafruit_VL53L1X& sensor,
  uint8_t address
) {
  if (!sensor.begin(address, &Wire)) {
    return false;
  }

  sensor.setTimingBudget(20);

  return sensor.startRanging();
}

bool initializeTofSensors() {
  pinMode(Pins::LEFT_XSHUT, OUTPUT);
  pinMode(Pins::RIGHT_XSHUT, OUTPUT);

  digitalWrite(Pins::LEFT_XSHUT, LOW);
  digitalWrite(Pins::RIGHT_XSHUT, LOW);

  delay(20);

  if (!initializeSingleTof(leftSensor, 0x30)) {
    return false;
  }

  delay(10);

  if (!initializeSingleTof(rightSensor, 0x31)) {
    return false;
  }

  delay(10);

  return true;
}

float calculateWallSteeringCorrection() {
  const DistanceReading& wall =
    followedWallReadingConst();

  if (
    !isDistanceFresh(wall) ||
    !isfinite(wall.filteredMm)
  ) {
    return 0.0f;
  }

  float errorMm =
    DistanceConfig::DEFAULT_WALL_DISTANCE_MM -
    wall.filteredMm;

  if (
    fabsf(errorMm) <=
    DistanceConfig::WALL_ERROR_DEADBAND_MM
  ) {
    errorMm = 0.0f;
  }

  /*
    تحديد سرعة تغير القراءة حتى لا تسبب قراءة مفاجئة
    أمرًا قويًا للسيرفو.
  */
  float safeRateMmPerSec = constrain(
    wall.rateMmPerSec,
    -500.0f,
    500.0f
  );

  float correctionDeg =
    DistanceConfig::WALL_KP * errorMm -
    DistanceConfig::WALL_KD *
    safeRateMmPerSec;

  return constrain(
    correctionDeg,
    -16.0f,
    16.0f
  );
}

float calculateCorridorCenteringCorrection() {
  if (
    !isDistanceFresh(robot.leftDistance) ||
    !isDistanceFresh(robot.rightDistance)
  ) {
    return 0.0f;
  }

  if (
    !isfinite(robot.leftDistance.filteredMm) ||
    !isfinite(robot.rightDistance.filteredMm)
  ) {
    return 0.0f;
  }

  /*
    موجب: الحائط اليسار أبعد من الحائط اليمين،
    أي أن الروبوت أقرب إلى اليمين ويجب أن يتجه يسارًا.

    سالب: الحائط اليمين أبعد،
    أي أن الروبوت أقرب إلى اليسار ويجب أن يتجه يمينًا.
  */
  float corridorErrorMm =
    robot.leftDistance.filteredMm -
    robot.rightDistance.filteredMm;

  if (
    fabsf(corridorErrorMm) <=
    DistanceConfig::CORRIDOR_CENTER_DEADBAND_MM
  ) {
    corridorErrorMm = 0.0f;
  }

  float correctionDeg =
    -DistanceConfig::CORRIDOR_CENTER_KP *
    corridorErrorMm;

  return constrain(
    correctionDeg,
    -DistanceConfig::MAX_CORRIDOR_CORRECTION_DEG,
    DistanceConfig::MAX_CORRIDOR_CORRECTION_DEG
  );
}

void followInnerWall(int speedPwm) {
  const DistanceReading& wall =
    followedWallReadingConst();

  if (
    !isDistanceFresh(wall) ||
    !isfinite(wall.filteredMm)
  ) {
    /*
      عند فقدان القراءة:
      نرجع السيرفو سنتر ونوقف المحرك بدل أن يبقى
      السيرفو مشدودًا يمين أو يسار.
    */
    setSteeringImmediate(
      SteeringConfig::CENTER
    );

    motorCoastStop();
    return;
  }

  float correctionDeg =
    calculateWallSteeringCorrection();

  float angle;

  if (robot.innerWallIsLeft) {
    angle =
      SteeringConfig::CENTER +
      correctionDeg;
  }
  else {
    angle =
      SteeringConfig::CENTER -
      correctionDeg;
  }

  /*
    هذه أهم حماية:
    حدود التتبع أضيق من الحدود الميكانيكية.
  */
  angle = constrain(
    angle,
    SteeringConfig::FOLLOW_LEFT_LIMIT,
    SteeringConfig::FOLLOW_RIGHT_LIMIT
  );

  setSteeringTarget(
    static_cast<int>(roundf(angle))
  );

  motorForward(speedPwm);
}

void beginCornerTurn() {
  robot.corner.turnLeft =
    robot.innerWallIsLeft;

  robot.corner.turnStartMs = millis();
  robot.corner.turnSettleReadings = 0;
  robot.corner.turnBrakingActive = false;

  resetYaw();

  setSteeringImmediate(
    robot.corner.turnLeft
      ? SteeringConfig::TURN_LEFT
      : SteeringConfig::TURN_RIGHT
  );

  applyMotorPwmImmediate(
    MotorConfig::TURN_FAST_SPEED
  );

  enterState(
    RobotState::TurningCorner
  );
}

void completeCornerTurn() {
  robot.corner.lastCornerMs = millis();
  robot.corner.stableWallBaselineMm = NAN;

  robot.corner.newWallReadings = 0;
  robot.corner.lastNewWallSampleMs = 0;

  /*
    إلغاء تأثير سرعة تغير القراءة القديمة،
    لأن القراءة قبل اللفة لا تمثل الحائط الجديد.
  */
  robot.leftDistance.rateMmPerSec = 0.0f;
  robot.rightDistance.rateMmPerSec = 0.0f;

  robot.leftDistance.previousFilteredMm =
    robot.leftDistance.filteredMm;

  robot.rightDistance.previousFilteredMm =
    robot.rightDistance.filteredMm;

  // رجوع فوري للسيرفو إلى السنتر
  setSteeringImmediate(
    SteeringConfig::CENTER
  );

  applyMotorPwmImmediate(
    MotorConfig::WALL_RECOVERY_SPEED
  );

  enterState(
    RobotState::FindingNewWall
  );
}
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
void loop() {
  updateTofSensors();
  updateImu();

  const DistanceReading& wall =
    followedWallReadingConst();

  /*
    تحديث خط أساس الحائط فقط أثناء التتبع الطبيعي.
  */
  if (
    robot.state ==
      RobotState::FollowingWall &&
    isDistanceFresh(wall) &&
    isfinite(wall.filteredMm)
  ) {
    if (
      isnan(
        robot.corner.stableWallBaselineMm
      )
    ) {
      robot.corner.stableWallBaselineMm =
        wall.filteredMm;
    }
    else {
      robot.corner.stableWallBaselineMm =
        0.90f *
          robot.corner.stableWallBaselineMm +
        0.10f *
          wall.filteredMm;
    }
  }

  switch (robot.state) {
    case RobotState::FollowingWall: {
      followInnerWall(
        MotorConfig::CRUISE_SPEED
      );

      bool lockoutFinished =
        millis() -
          robot.corner.lastCornerMs >
        CornerConfig::CORNER_LOCKOUT_MS;

      if (lockoutFinished) {
        bool readingReady =
          isDistanceFresh(wall) &&
          isfinite(wall.openingFilteredMm) &&
          !isnan(
            robot.corner.stableWallBaselineMm
          );

        if (readingReady) {
          float openingRiseMm =
            wall.openingFilteredMm -
            robot.corner.stableWallBaselineMm;

          if (
            openingRiseMm >=
            CornerConfig::
              MIN_RELATIVE_OPENING_RISE_MM
          ) {
            beginCornerTurn();
          }
        }
      }

      break;
    }

    case RobotState::TurningCorner:
      updateCornerTurn();
      break;

    case RobotState::FindingNewWall:
      updateFindingNewWall();
      break;

    case RobotState::AligningToWall:
      updateWallAlignment();
      break;

    case RobotState::EmergencyStop:
      motorCoastStop();

      setSteeringImmediate(
        SteeringConfig::CENTER
      );

      break;

    default:
      motorCoastStop();

      setSteeringImmediate(
        SteeringConfig::CENTER
      );

      break;
  }

  updateMotorActuator();
  updateSteeringActuator();

  delay(1);
}

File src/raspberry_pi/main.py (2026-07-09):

import time
from camera import Camera
from lane import detect_lane
from decision import make_decision
from serial_comm import SerialComm

def main():
    camera = Camera()
    uart = SerialComm()

    print("WRO Raspberry Pi program started")

    try:
        while True:
            frame = camera.read()

            if frame is None:
                uart.stop()
                time.sleep(0.2)
                continue

            lane_error = detect_lane(frame)
            steer, speed = make_decision(lane_error)

            uart.send_drive_command(steer, speed)
            time.sleep(0.05)

    except KeyboardInterrupt:
        print("Keyboard interrupt")

    finally:
        camera.release()
        uart.stop()
        print("Program stopped")

if __name__ == "__main__":
    main()

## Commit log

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2026-06-26 Document hardware components and their functions
    Added detailed descriptions of hardware components including the main controller, vision computer, sensors, motor driver, and mechanical platform.
2026-06-26 Revise current hardware status and battery evaluation
    Updated the current hardware status to reflect progress on component selection and assembly, as well as ongoing evaluations for the final battery solution.
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2026-07-08 Add steering test documentation
    Added documentation for the initial steering servo test
2026-07-08 Add steering test documentation
    Added documentation for the initial steering servo test.
2026-07-08 Refactor steering_test.ino and clean up comments
    Removed comments in Arabic and adjusted the code structure.
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2026-07-08 Add MPU6050 validation test documentation
    Added detailed validation test documentation for MPU6050 IMU, including objectives, hardware configuration, software description, test procedure, expected results, validation results, engineering not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
2026-07-08 Add motor test code for L298N driver
    This code tests the L298N motor driver by controlling motor direction and speed.
2026-07-08 Add README for L298N motor driver validation test
    Added README.md for L298N motor driver validation test, detailing objectives, hardware configuration, software description, test procedure, expected output, validation results, engineering notes, and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
2026-07-08 Revise README for DC Motor Driver Validation Test
    Updated README to clarify motor driver testing and objectives.
2026-07-08 Add engineering calculations for robot design
    This document outlines the engineering calculations for the WRO Future Engineers robot, including robot dimensions, weight, wheel dimensions, circumference, and gear ratio.
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2026-07-08 Add README for TCS34725 Color Sensor validation test
    Documented the validation test for the TCS34725 color sensor, including objectives, hardware configuration, software description, test procedure, expected output, test results, engineering notes, and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
2026-07-08 Clarify gearbox inspection and future calculations
    Updated the gearbox section to clarify the manual inspection process and added future calculations to be included.
2026-07-08 Revise power system selection and engineering justification
    Updated engineering justification and power system selection details, including alternatives evaluated and final decision on battery and voltage regulation.
2026-07-08 Add motor driver selection decision to documentation
    Documented the decision-making process for motor driver selection, including engineering requirements, alternatives evaluated, final decision, future improvements, and trade-offs.
2026-07-08 Document steering servo selection process and trade-offs
    Added detailed analysis and selection criteria for steering servo.
2026-07-08 Document DC motor selection process and criteria
    Added a section for DC motor selection, detailing engineering requirements, alternatives evaluated, final decision, justification, and trade-offs.
2026-07-08 Document camera selection decision in DECISIONS.md
    Added detailed decision-making process for camera selection, including engineering requirements, alternatives evaluated, final decision, justification, and trade-offs.
2026-07-08 Document distance sensor selection decision
    Added decision documentation for distance sensor selection, including engineering problem, requirements, alternatives evaluated, final decision, justification, challenges, and trade-offs.
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2026-07-08 Document color sensor selection decision in DECISIONS.md
    Added decision details for color sensor selection, including engineering requirements, alternatives evaluated, final decision, justification, and trade-offs.
2026-07-08 Document decisions on battery, chassis, and software
    Added decisions on battery, chassis, communication protocol, and software architecture with evaluations and trade-offs.
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2026-07-09 Add I2C scanner for TOF validation
    This code initializes the I2C bus and scans for connected devices, printing their addresses to the serial monitor.
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2026-07-09 Add README for TOF400C-VL53L1X sensor investigation
    Document investigation results and future plans for the TOF400C-VL53L1X distance sensor integration into the WRO Future Engineers autonomous vehicle.
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2026-07-09 Add README for HC-SR04 Ultrasonic Sensor validation
    Documented the validation process and integration plan for the HC-SR04 ultrasonic sensor, including wiring, software operations, and future improvements.
2026-07-11 Add VL53L1X sensor demo code
    This code initializes the Adafruit VL53L1X distance sensor, sets up serial communication, and starts ranging. It also includes error handling for sensor initialization and distance measurement.
2026-07-11 Revise README for TOF400C-VL53L1X sensor validation
    Updated README to reflect validation process and results for the TOF400C-VL53L1X distance sensor, including changes in wiring, initialization challenges, and future integration plans.
2026-07-22 Remove obsolete CAD files from HARDWARE.md
    Removed outdated 3D model files from documentation.
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2026-07-23 Revise WIRING.md for clarity and detail
    Updated the wiring documentation to clarify connections and components. Added detailed tables for power distribution, main controllers, motor and steering control, sensor connections, GPIO assignment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
